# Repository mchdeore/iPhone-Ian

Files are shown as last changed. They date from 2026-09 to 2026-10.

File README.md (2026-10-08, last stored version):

# iPhone Accessibility Robot (`iPhone-Ian`)

A physical robot that operates a **stock, unmodified iPhone** by tapping its
touchscreen, driven by a vision-based AI agent. You give it high-level commands
like `login`, `enter`, or `exit`, and it locates the right on-screen targets,
moves a capacitive stylus to them, and taps — pulling secrets (e.g. login
credentials) from a host-side vault so you never hand-type them again.

> Working title. The repo name (`iPhone-Ian` → "iPhonian") is a placeholder we
> can rebrand later.

## Why a physical robot (and not software)

The phone is treated as an **opaque black box**: no jailbreak, no MDM, no
developer provisioning, nothing installed on it. On a stock iPhone there is no
ADB-style control surface, so a physical actuator that just *touches the glass*
is the most general way to automate an arbitrary device. See
[`specs/00-charter.md`](specs/00-charter.md) for the full rationale.

## The three things set in concrete

1. **Target device: iPhone, 100%.** iOS-only. (The Android survey in
   `research/` is legacy background — see note below.)
2. **Actuation: a tap robot, borrowing heavily from Tapster + the Instructables
   "Screen Tapping Robot."** Reuse existing open designs (Tapster's Push Button
   Robot / Sidekick lineage, the 3D-printable Cartesian gantry) rather than
   reinventing. See [`specs/01-hardware.md`](specs/01-hardware.md).
3. **Training: an ML rig / data-collection app** so the agent learns to drive
   the phone reliably. See [`specs/02-firmware-and-software.md`](specs/02-firmware-and-software.md).

## Repository layout

Split by owner so each of us can find the other's work. Shared material stays at the top.

| Who | Owns | Start here |
|---|---|---|
| **Aria** | Hardware: CAD, parts + sourcing, assembly | [`aria/README.md`](aria/README.md) |
| **Marc** | Software: OCR/vision, training loop, agent, host control, credentials | [`marc/README.md`](marc/README.md) |

```
iPhone-Ian/
├── README.md                      # this file
├── DEVELOPMENT.md                 # staged build pipeline (shared)
├── specs/                         # original specifications (shared)
│   ├── 00-charter.md              # scope, decisions, security, roadmap
│   ├── 01-hardware.md             # hardware research + citations (v2 design: aria/)
│   └── 02-firmware-and-software.md# firmware + software + ML
├── research/                      # background research notes (shared)
├── aria/                          # HARDWARE (Aria)
│   ├── hardware-concept-v2.md     # requirements, design, parts list w/ links, open questions
│   ├── LOG.md                     # dated decisions + to-dos
│   └── cad/v2_0_layout.py         # CoreXY layout model (build123d)
└── marc/                          # SOFTWARE (Marc)
    ├── DEVLOG.md                  # Marc's dev log
    └── parts-v1/                  # v1 gantry CAD (retired by v2)
```

> The research is split into two parts, matching the two specs: **hardware /
> physical build** (`01-hardware.md`) and **firmware / software / ML**
> (`02-firmware-and-software.md`). All reusable-parts research and citations now
> live inside those two docs.

## Relationship to HomeLab

[HomeLab](https://github.com/mchdeore/HomeLab) is the separate, overarching
project: the permanent home PC / Linux server and its CI/CD. This accessibility
robot is intended to be *built on top of* that server (the host that runs the
agent and holds the credential vault lives there), but its research and design
live here, on their own.

## Status

Design stage (2026-10-02). Hardware v2 is proposed: a 2-phone CoreXY gantry, ~34 × 32 × 5 cm, ~C$325 + tax, with
1 phone first for testing. See `aria/hardware-concept-v2.md`. Software planning is under way in `marc/`.
Nothing is built yet.

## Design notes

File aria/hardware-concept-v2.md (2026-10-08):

# Hardware Concept v2: requirements, design, parts

**Author:** Aria (hardware lead) · **Updated:** 2026-10-02 · **Status:** agreed on the 2026-10-02 call. 2-phone capacity, first build tested with 1 phone

This replaces the hardware direction in `specs/01-hardware.md` §0 and Marc's v1 scaffold (now `marc/parts-v1/`). The order is requirements first, then the design, then the parts.

---

## 1. Requirements

| # | Requirement | Drives |
|---|---|---|
| R1 | **2 iPhones of any model** at once (start testing with 1), held so they can't budge. More later = longer rails | Bed size, slot design, expandability |
| R2 | **Screen inputs only:** tap, long-press, swipe/drag. No physical buttons, no multi-touch. Phones are kept awake and charged by other means. | One stylus with hold-down |
| R3 | Typing at **2–3 taps/s** | Motion speed, tap actuator |
| R4 | Lives in a **drawer/cabinet**, runs **quietly**, as **slim** as possible (target: thick laptop) | Height budget, the camera question, drivers |
| R5 | **3D-print as much as possible**, low cost (split between us) | Part strategy, sourcing |

## 2. The camera decision (Marc: this is yours to confirm)

An overhead webcam that sees 2 phones side by side has to sit **~14 cm above the glass** (a typical ~70° webcam
covering ~190 mm), or ~28 cm for 4. Both fail R4 (the machine is ~5 cm tall).

**Proposal: no camera.** Get each phone's screen image directly instead:
- **USB capture.** The phones are plugged in for charging anyway, and macOS can capture an iPhone's screen over
  the cable (QuickTime / AVFoundation). The phone only needs a one-time "Trust this computer".
- **AirPlay mirroring** to a receiver on the host (e.g. UxPlay on Linux), one instance per phone.

Both are built into iOS, so nothing is installed on the phone. On top of fixing the height, it gives:
pixel-perfect input for OCR, no glare or lens calibration, and the tap results show up directly in the feed.
Calibration becomes: tap known gantry points on a Safari calibration page and read where they land.

**Fallback if this doesn't work:** a small camera riding on the gantry that scans each screen in several shots.
It fits the height, but it's slower and makes the OCR harder.

**Question for Marc:** can you get 2 simultaneous screen feeds on your setup (Mac and/or HomeLab)? 1 is enough for first tests.

## 3. Concept

```
 back:  [idlers]━━━━━━ belts ━━━━━━[motor A]
        ═══════ long rail (MGN9) ═══════
        ┃      ┌────┐  ┌────┐         ┃
        ┃bridge│ 📱 │  │ 📱 │         ┃   bridge spans front↔back,
        ┃ +    │    │  │    │         ┃   travels left↔right;
        ┃stylus└────┘  └────┘         ┃   stylus travels along bridge
        ═══════ long rail (MGN9) ═══════
 front:                      [motor B]
```

- **Bed:** 2 printed phone slots (~95 mm pitch, fits up to Pro Max), phones face up in portrait.
  - Each slot has TPU corner pads, a spring-loaded end clamp, a **pocket for the camera bump** (so the phone doesn't rock), and a notch for the charging cable.
  - Clamping is at the **corners and ends only**: side jaws would press the power and volume buttons.
  - More phones = longer rails: set `N_PHONES` in `aria/cad/v2_0_layout.py` and the frame resizes (4 phones = 53 × 32 cm).
- **Motion: CoreXY.** Both motors stay fixed at one end of the frame. The belts pull **both ends** of the bridge
  evenly, so it can't rack, and nothing heavy rides on the bridge, so it stays thin and quiet.
- **Rails:** MGN9 linear rails. They're low, quiet and don't bind, and they replace printed bushings.
- **Tap (Z):** a micro servo lying flat lifts a lever carrying a **spring-loaded conductive stylus** with a **ground
  wire** to controller GND.
  - The spring absorbs thickness differences between models, so one tap height works for all phones.
  - The servo can hold the stylus down for long-press and swipe.
  - A ~10 mm key-to-key hop plus a tap takes ~0.3 s, which meets R3.
- **Controller:** MKS DLC32 (ESP32) running **FluidNC**: CoreXY kinematics and RC-servo Z are set in a config file, with
  no custom firmware. TMC2209 drivers (StealthChop) keep it quiet. (Uno + stock GRBL would need
  two patched firmware forks merged to do CoreXY + servo.)
- **Size:** **~34 × 32 cm footprint, ~5.0 cm tall** (checked in `aria/cad/v2_0_layout.py`: 10 mm under-bridge clearance, every screen corner reachable, no collisions). The minimum height is set by the phones (~9 mm), clearance under
  the bridge, and the bridge itself, so it's thicker than a laptop but fits a deep drawer.

### 3.1 Software ↔ hardware hand-off

The robot exposes only:

```
move(x, y)   tap()   down()   up()   home()
```

These are sent as G-code over USB serial, in mm in the machine frame. Marc builds against this immediately; the
hardware just has to obey it. All intelligence stays on the host.

### 3.2 Parameters the hardware exposes (for Marc's overview)

These are set in FluidNC's `config.yaml` or sent as G-code. The host reads or sets them; nothing is hard-coded in firmware.

| Parameter | Meaning | Typical |
|---|---|---|
| Machine frame | Origin = home corner, X along the phone row, Y along the bridge, mm | after `$H` |
| Travel limits | Soft limits; moves past them are rejected | X ≈ ±86 mm stylus reach (2 phones), Y ≈ ±82 mm |
| Slot origins | Per-phone offset + homography from screen px to machine mm (host-side, from calibration) | 1 per slot |
| Feed rate / accel | Move speed and acceleration | ~150–300 mm/s, ~2000 mm/s² (tune for quiet) |
| Tap depth | Servo "down" angle; the spring absorbs ±3 mm | calibrated per build |
| Lift height | Servo "up" angle: tip ~3 mm above the glass | |
| Dwell | Time held down for a tap vs a long-press | ~60 ms tap, ≥500 ms long-press |
| Swipe | down → `G1` move at a set feed → up | |
| Homing | `$H` against the X/Y endstops at power-on | |
| Status | `?` returns position + state (Idle/Run/Alarm) | polled by the host |

## 4. Review of the current CAD branch

The v1 scaffold (`marc/parts-v1/`, build123d) is a good pipeline, but the design doesn't close:

1. **The heights don't fit together.**
   - The X rods are centred 16 mm up, but phone glass is at ~15 mm (bare) and ~19 mm (cased), so the rods and carriage pass through the phone.
   - The stylus holder hangs 38 mm below the carriage, which puts it through the baseplate.
2. **The Y axis will jam.** One belt drives one side of a ~200 mm bridge riding single 12 mm bushings. That's ~17× the
   bearing length vs the usual ≤2× rule, so it will jam. CoreXY fixes this by driving both ends.
3. **The docs disagree.** `main` says Instructables lead-screw; the branch's §0 says pancake motors, printed bushings and
   a 72 mm X reach; `DEVLOG`/`params.py` say oilite bushings and a 150×160 mm area. The parts-list rod lengths (200/120 mm)
   don't match the model (230/210 mm).
4. **The servo is in two places.** `5_stylus_holder.py` hangs the servo below; the assembly preview mounts it on the side.
5. **Missing:**
   - cable management to the moving carriage
   - grub screws threaded straight into PETG will strip, so they need heat-set inserts or nut traps
6. **The tooling only runs on a Mac:** zsh aliases with hard-coded paths. It needs a cross-platform runner.

**Carries over:** the code-CAD workflow, `params.py` as the single source of dimensions, and the spring-stylus idea.
**Retired:** the rod/bushing gantry parts (1, 3, 4) and the assembly preview.

## 5. Parts to buy: verified listings (checked 2026-10-01, CAD, before tax)

Every listing was opened and its option and price checked. **Choose the variant shown in "Pick".**

### AliExpress

| Part | Link | Pick | C$ | Aria (work) | Marc (work) |
|---|---|---|---|---|---|
| Controller | [MKS DLC32 V2.1](https://www.aliexpress.com/item/1005003528786927.html) | "MKS DLC32 V2.1" (board only) | 26.85 |  |  |
| Drivers | [BIGTREETECH TMC2209 (official)](https://www.aliexpress.com/item/33028050145.html) | 4PCS | 23.21 |  |  |
| Motors | [STEPPERONLINE 17HE08-1004S (official)](https://www.aliexpress.com/item/1005004708155105.html) | 1PC ×2 (23 mm, 1 A, 20 mm shaft) | 24.16 |  |  |
| Servo | [MG90S](https://www.aliexpress.com/item/1005008626768357.html) | 2 pcs, **180°** (360° = continuous, useless) | 5.89 |  |  |
| PSU | [24 V adapter](https://www.aliexpress.com/item/4000521124523.html) | 3A, US Plug, 24V | 10.93 |  |  |
| 5 V buck (servo) | [Mini560 **PRO**](https://www.aliexpress.com/item/1005006537133858.html) | 5 V (PRO = 6–30 V in; plain Mini560 can't take 24 V) | 5.07 |  |  |
| Endstops | [mechanical, with cable](https://www.aliexpress.com/item/1005007505049085.html) | 3 pcs | 3.97 |  |  |
| Rails | [MGN9 (Magic Dragon)](https://www.aliexpress.com/item/1005002721523331.html) | MGN9H: "230mm with Block" ×3 | 39.15 |  |  |
| Bridge | [2020 V-slot (same store)](https://www.aliexpress.com/item/1005003311298946.html) | 240mm, 2020V | 6.39 |  |  |
| Belt | [GT2 rubber/aramid](https://www.aliexpress.com/item/1005008463979470.html) | 6mm, 5 meters | 6.16 |  |  |
| Motor pulleys | [Mellow 20T 5 mm bore (official)](https://www.aliexpress.com/item/33023279793.html) | For 6mm, 2Pcs | 6.86 |  |  |
| Idlers | [GT2 20T 3 mm bore](https://www.aliexpress.com/item/32817328238.html) | "20T W6 B3 GT2 T" ×6, "20T W6 B3 without T" ×4 | 25.62 |  |  |
| Heat-set inserts | [M3 brass](https://www.aliexpress.com/item/1005010325121347.html) | M3 | 7.54 |  |  |
| Screws | [M3 DIN912](https://www.aliexpress.com/item/1005001785690381.html) | M3 × 8, 12, 16, 20, 25, and 50 (×2, corner idler bolts) | ~14 |  |  |
| Nyloc nuts | [M3](https://www.aliexpress.com/item/32798773566.html) | M3 | 2.83 |  |  |
| Shim washers | [M3 0.5 mm](https://www.aliexpress.com/item/1005002046188859.html) | M3, 0.5 mm (idler spacing, inner race only) | 2.38 |  |  |
| T-nuts | [M3 for 2020](https://www.aliexpress.com/item/4000726230157.html) | M3 | 2.94 |  |  |
| Brass tube | [0.25 mm wall](https://www.aliexpress.com/item/1005005307061739.html) | 5 mm OD (4.5 ID fits the stylus tip stem) | ~7.41 |  |  |
| Springs | [0.5 mm wire](https://www.aliexpress.com/item/1005005312536098.html) | ~7 mm OD × 20 mm (over the tube) | ~5.28 |  |  |
| Wire | [silicone](https://www.aliexpress.com/item/1005006250522147.html) | 26AWG, 5 m | 3.78 |  |  |
| Servo extension | [listing](https://www.aliexpress.com/item/1005008268927795.html) | 1to1, 50 cm | 2.29 |  |  |
| DC jack adapter | [listing](https://www.aliexpress.com/item/1005007895939239.html) | female 5.5×2.5 | 2.04 |  |  |
| **AliExpress total** | | | **~235** (~266 with HST) | | |

### Elsewhere

| Part | Where | C$ | Aria (work) | Marc (work) |
|---|---|---|---|---|
| Stylus tips, 6 mm mesh with threaded metal stem | [Amazon.ca PATIKIL 5-pack](https://www.amazon.ca/dp/B0FNX4LB7H) (AliExpress only has Apple Pencil nibs, which are active and won't work) | 8.49 |  |  |
| Rail risers, 6061 10×20 mm, 2 pieces ~240 mm (one 500 mm bar cut in half) | [Amazon.ca COYOUCO 10×20×500](https://www.amazon.ca/dp/B0GS1P1J79) ×1, or Metal Supermarkets (Kitchener) | ~27 |  |  |
| Base plate, 3 mm aluminium ~341×320 with slotted holes | JLCCNC quote **after** the plate CAD exists | ~50 incl. shipping |  |  |

**Whole build ≈ C$325 + tax, split between Aria and Marc.** Both of us have 3D printers and essentially free filament.

**Work sourcing:** each of us ticks what we can get through work in the **Aria (work)** / **Marc (work)** columns.
Anything ticked comes off the order.

**Printed (Centauri, CF-PETG / TPU):** corner idler posts + top plates + side walls, motor clamp bars + legs, motor B spacer,
bridge end blocks + top plates, toolhead plate + lever + stylus sleeve, belt clamp, endstop mounts, 2 phone slots,
cable guides, feet, controller box.

**Assembly notes:**
- Mount motor pulleys **hub-up** (teeth toward the motor) so they line up with the belts.
- Every idler bolt is clamped **top and bottom**. Shim washers touch only the bearing's inner race.
- Confirm on arrival which pin on the DLC32 drives the servo and how the board takes power (barrel jack vs screw terminal).

**Security:** run the controller over USB only, with its Wi-Fi off. Remote access goes through the host (SSH / WireGuard / Tailscale).
FluidNC's network control has no real authentication.

## 6. Sourcing

- **JLCCNC** is the default for metal (price). Bundle the JLCMC rails, pulleys and fasteners into the same order.
- **SendCutSend** only for rush parts.
- **AliExpress** for electronics, motors, motion parts and hardware (one order; rails + extrusion ship together from Magic Dragon).
- **Base from day one is a 3 mm aluminium plate cut by JLCCNC.** Rail-riser, motor and slot holes are **slots, not round holes**,
  so a few mm of CAD error is adjusted out instead of forcing a reorder. Order it only after the assembly is checked in Onshape.
  Later upgrades: a bent aluminium tray (base + raised rail ledges in one part), a bent-channel bridge, motor plates.
  Later, possibly a JLC flex-PCB ribbon to the carriage.
- Keep precision holes on flat sections, not ones that depend on a bend's position.

## 7. Open questions for Marc

1. Do 2 simultaneous screen feeds (USB or AirPlay) work on your setup? This decides the camera question.
2. Bare phones only, or cases too? (The spring absorbs ~3 mm; cases also widen the slots.)
3. ~~OK for me to take over the CAD branch?~~ **Agreed 2026-10-02.** Repo split into `aria/` and `marc/`.
4. ~~Budget?~~ **Agreed 2026-10-02:** ~C$325 + tax, split between us.
5. Is the hand-off in §3.1 enough for your side?
6. Security: OK with USB-only to the controller and all remote access through the host?

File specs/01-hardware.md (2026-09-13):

# Hardware Build Specification

**Scope:** everything physical — the machine, its motion, the tap, the phone
mount, the camera, and the CAD files to build it all. Firmware and code live in
[`02-firmware-and-software.md`](02-firmware-and-software.md).

> All external links are collected with citations in §11. User-supplied CAD links
> are tagged `[user-provided]` and listed in §5.

---

## 0. FINAL LOCKED DESIGN — v1 (2026-09-09)

**Locked by the owner.** Priorities: **quiet, small, easy to work on** (not powerful,
not high-accuracy — the camera closes the loop, §8). This section supersedes any
conflicting option below; the multi-touch / two-arm (Sidekick) path and the
**lead-screw** drive are **retired** for v1. §§1–11 are retained as research/rationale.

### 0.1 Architecture

A **belt-driven Cartesian gantry** with a single effector. One motor per axis — maps
directly onto GRBL, zero custom firmware.

- **Y axis** (long, ~150 mm reach): two 8 mm smooth steel rods along the phone's
  length carry a cross-beam on **printed bushings**; Y motor is fixed to the frame.
- **X axis** (short, ~72 mm reach): two short 8 mm rods on the beam; a **pancake**
  NEMA 17 rides here on printed bushings (minimizes moving mass → quieter, smaller).
- **Z / tap:** MG90S metal-gear servo on the X carriage, stylus arm on the horn.
- Grounded capacitive stylus tip (ground wire to controller GND — mandatory, §3.1).

### 0.2 Print-max BOM — buy only precision-critical parts

**Philosophy:** 3D-print everything structural (free); buy only what carries precision
or can't be printed. The **running surface is a bought 8 mm smooth steel rod**; the
bushings that ride it are **printed** (steel rod = the precision, plastic-on-steel
bushing = free and quiet — no stick-slip). `ponytail:` printed bushings wear under
continuous use — ceiling is finite service life; upgrade path is drop-in IGUS DryLin
bushings of the same 8 mm bore, no redesign.

**Buy (precision-critical / unprintable):**

| Part | Qty | Why bought |
|---|---|---|
| NEMA 17 pancake stepper, 0.9–1.0 A | 2 | Electromagnetic |
| MG90S metal-gear micro servo (tap/Z) | 1 | Electromechanical |
| Arduino Uno + CNC Shield V3 | 1 | Electronics |
| TMC2209 "silent" driver (StealthChop2) | 2 | Quiet stepping |
| 12 V regulated PSU (~2 A) + 12→5 V buck | 1 | Clean power, servo isolation |
| **8 mm smooth steel rod** (2×~200 mm Y, 2×~120 mm X) | 4 | **The precision running surface** |
| GT2 6 mm belt | 1 | Reinforced — can't print |
| 20T bore-5 GT2 pulleys + 623 idler bearings | set | Precision tooth mesh / rolling |
| Microswitch endstops (X-min, Y-min) | 2 | Repeatable `$H` homing |
| M3 heat-set inserts + M3/M5 fasteners | set | Serviceable printed joints |
| Capacitive stylus tip + ground wire | 1 | The effector |
| Rubber/sorbothane feet (or print in TPU) | 4 | Isolate base = biggest quiet win |

**Print (free):** baseplate, Y cross-beam, X carriage, **the linear bushings**, all
motor/idler/endstop mounts, belt clamps + tensioner, phone cradle (tripod-clamp
model, §5.1), camera arm, stylus arm. Optionally print GT2 pulleys, but bought metal
ones avoid tooth backlash for ~$2.

**Controller/software link:** USB serial to GRBL now; ESP32 + FluidNC is the drop-in
upgrade if USB-C / wireless is wanted later (sw spec §4.1).

### 0.3 Reused CAD (from §5.1) / retired items

- **Reuse:** parametric NEMA 14/17 mount (→ motor mounts), SG90 model (→ MG90S mount
  fit), tripod phone clamp v2 (→ phone cradle), **linear sliding system + DSLR slider
  (→ rod + printed-bushing carriage reference — now directly relevant)**.
- **Retired (lead-screw):** screw+stepper coupling, MK4 Z-screw motor cover.

### 0.4 Approximate cost (print-max; excl. phone / camera / laptop; printing free)

| Group | Items | ~USD |
|---|---|---|
| Core electronics + motors | Uno+shield, 2× TMC2209, 2× pancake NEMA 17, MG90S, 12 V PSU, buck | **~$79** |
| Precision motion | 4× 8 mm steel rod, GT2 belt + pulleys + 623 idlers, 2× endstops | **~$23** |
| Fasteners + effector + feet | heat-set inserts/screws, stylus tip + wire, rubber feet, USB cable | **~$18** |
| **Total** | | **~$120** |

Low–high range **≈ $100–150** depending on source (AliExpress budget ↔ Amazon/genuine).
Down from the ~$155 MGN9 build by **printing the bushings + structure** and letting a
cheap steel rod carry the precision. Figures are approximate hobby-market estimates,
not live quotes — a sourced, link-by-link list is the next deliverable.

---

## 🎯 1. Design source of truth (current)

**Instructables — "Screen Tapping Robot"** → https://www.instructables.com/Screen-Tapping-Robot/

Our mechanical baseline. A 3D-printable, stepper-driven **Cartesian XY gantry**
with a stylus that taps the screen — exactly our target architecture, and the
maker reports it working.

**Verified from the build description:**
- **X-axis:** NEMA 17 stepper driving a **lead screw**, riding on **two
  8 mm × 300 mm stainless precision shafts** with **linear ball bearings**; the
  X-axis carries the Y-axis + stylus (built stiff on dual shafts for that reason).
- Cartesian lead-screw motion (not delta, not CoreXY).

**Still to extract from the build page** (Instructables blocks scraping — pull by
hand): Y-axis mechanism + motor, Z/stylus actuation, controller + firmware,
grounding, full BOM, STL/CAD files, work-area dimensions.

---

## 2. System architecture

Five physical subsystems. Each maps to reusable CAD/parts in §4–§5.

| Subsystem | Function | Baseline choice |
|---|---|---|
| **X axis** | Move stylus left/right across screen | NEMA 17 + lead screw on dual 8 mm shafts (SoT) |
| **Y axis** | Move stylus up/down the screen | NEMA 17 + lead screw or belt (TBD from SoT) |
| **Z / tap** | Bring stylus into contact & lift | Servo pen-lift **or** passive spring-Z stylus (§6) |
| **Phone mount** | Hold an iPhone rigidly & repeatably | Adjustable printed clamp (§5) |
| **Camera mount** | Fixed overhead view of the screen (the agent's eyes) | Printed arm / slider rail (§5) |

Design driver: **rigidity + repeatability**, because calibration (camera→screen→
gantry) is the real accuracy bottleneck, not raw motor resolution (§8).

---

## 3. Prior-art lessons we inherit (free knowledge)

From **Tappy / Tapsterbot** (delta-robot phone tappers — different kinematics, same
touch problem). See software spec §2 for their reusable *code*.

1. **Grounding is mandatory — confirmed by multiple builders.** The stylus must be
   electrically tied to the controller/USB ground or the capacitive screen won't
   register touches. Tappy's own docs: *"Make sure that phone recognises stylus
   touches (it must be grounded to arduino GND)."* [guntiss/tappy] **→ We design an
   explicit ground path from day one.**
2. **Joint slop kills accuracy.** Tappy fixed positioning slop by swapping
   ball-joints → neodymium magnets and metal → plastic linkages. A stiff Cartesian
   gantry sidesteps most of this — an argument for our architecture.
3. **Contact is capacitive, not pressure-based** (see
   `../research/02-mechanical-architecture-notes.md`). We only need *consistent*
   contact geometry, not force — so a light, repeatable tap depth is enough.

### 3.4 Tapster design lineage — borrow as much as possible ⭐

Tapster (https://tapster.io, by Jason Huggins — creator of Selenium/Appium) is a
company that has worked on **almost nothing but phone-tapping robots for years**,
and much of it is open. **Policy: reuse their designs wherever we legally can**
(check each repo's license), rather than reinventing.

Their lineage, simplest → most capable:

- **Push Button Robot** — a small-footprint, minimal, ~two-rail/two-track tapper.
  *[user-reported; verify specifics on tapster.io + the `tapsterbot` GitHub org.]*
  **This is our most attractive MVP target:** tiny, few parts, and easy to drive
  deterministically (see sw spec §4.1). Start here, scale up only if needed.
- **Sidekick** — **two independent arms**, each with its own Z-axis servo (the host
  maps left arm = servo `s3`, right arm = servo `s6`). Two effectors ⇒ a path to
  **2-point multi-touch** (pinch/rotate) later. Web controller repo:
  https://github.com/tapsterbot/controller
- **Tapster / Tapster-2** — the flagship **delta** tapper (open hardware + software).
- **Valet** — their **current Raspberry-Pi-based** product. Notable because it puts
  the **Pi as the host** — the same split we plan (Pi/HomeLab host drives a dumb
  controller).
- **BitBeamBot** — the ancestor that started the lineage (built to play Angry Birds).

**Strategy:** prototype at **Push Button Robot** scale/simplicity, reuse Tapster's
open hardware + host stack, and only move to a Cartesian gantry or a two-arm
(Sidekick-style) rig if the task demands larger reach or multi-touch. Links in §11.

---

## 4. Mechanics — reuse ecosystems (don't design linear motion from scratch)

- ⭐ **OpenBuilds** — V-Slot™ / C-Beam™ extrusion, wheels, lead screws, NEMA 17
  mounts, gantry plates. CC BY-SA; large parts market. https://openbuilds.com
- ⭐ **OpenBuilds ACRO** — a pen-plotter-sized XY gantry kit ≈ our machine;
  adaptable to any size. Assembly: [Maker Hardware ACRO manual]; ACRO pen-plotter
  build w/ GRBL + Pi: [ACRO Openbuilds Pen Plotter].
- **openBrushograph** — 3D-printable XY gantry + Z, FreeCAD/OpenSCAD sources.
  https://github.com/openBrushograph/openBrushograph_hardware
- **CNC pen-plotter references** — https://github.com/DAguirreAg/CNC-pen-plotter ·
  https://github.com/thrly/pen-plotter-resources
- **openbuilds-parts** (OpenSCAD brackets) — https://github.com/mhgreen/openbuilds-parts

**Decision to make:** keep the SoT's printed shaft + lead-screw frame (cheapest,
fully printable) **vs.** OpenBuilds extrusion (stiffer, faster to assemble). Our XY
load is a featherweight stylus, so recommend prototyping on **ACRO** to de-risk
motion, then optimize cost.

---

## 5. CAD file library

Ready-to-use models mapped to subsystems. **Editability:** GrabCAD models are often
**STEP** (parametric-editable); Printables are usually **STL** (mesh). Verify
license on each before use.

### 5.1 User-provided links `[user-provided]`

| Part | Use in our build | Link | Notes |
|---|---|---|---|
| Medium-format CNC machine w/ ATC spindle | Reference for a full XY(Z) gantry + mounts | https://grabcad.com/library/custom-designed-medium-format-cnc-machine-with-atc-spindle-1 | Bigger than we need; harvest gantry/mount geometry |
| **SG90 micro servomotor** | The **tap (Z) actuator** model for assembly fit | https://grabcad.com/library/sg90-micro-servomotor-1 | Pairs with ServoEasing in sw spec |
| Rubik's Cube solver (full setup) | Reference: multi-motor + gripper + frame + vision | https://grabcad.com/library/rubik-s-cube-solver-full-setup-1 | Great CV-robot mechanical precedent |
| **Parametric NEMA 14/17 stepper mount** | **X/Y motor mounts** (parametric = resize to our frame) | https://grabcad.com/library/parametric-stepper-motor-nema-14-17-mount-1 | Directly reusable |
| **DSLR slider module** | **Linear axis** reference (carriage + rail) | https://grabcad.com/library/dslr-slider-module-1 | Camera-slider = a single linear axis |
| **Linear sliding system** | **X/Y linear-motion** carriage/bearing block | https://grabcad.com/library/linear-sliding-system-1 | Core motion element |
| **Screw + stepper motor coupling** | Couple NEMA 17 shaft → lead screw | https://www.printables.com/model/404241-screw-and-stepper-motor-coupling | Directly reusable |
| **MK4 Z-screw motor cover** | Tidy/protect the Z lead-screw + motor | https://www.printables.com/model/454773-mk4-z-screw-motor-cover | Cosmetic/protective |
| **Adjustable tripod phone clamp v2** | The **iPhone mount** (adjustable width) | https://www.printables.com/model/25969-tripod-mobile-phone-clamp-v2 | Directly reusable for phone cradle |

> Status: links recorded as provided; **not yet individually opened/verified**
> (GrabCAD/Printables may gate downloads behind login). Verify geometry, scale, and
> license before printing. Mesh (STL) parts may need re-modeling if dimensions must
> change — prefer the STEP/parametric ones for load-bearing structure.

### 5.2 Model libraries to search for the rest

- **Printables** https://www.printables.com · **GrabCAD** https://grabcad.com ·
  **Thingiverse** https://www.thingiverse.com · **Thangs** https://thangs.com
- **Hardware w/ CAD (for a correct BOM):** McMaster-Carr, Misumi (every
  screw/bearing/shaft as a STEP).

### 5.3 CAD tools

- **FreeCAD** (parametric, open) · **OpenSCAD** (code-CAD; great for parametric
  brackets — openBrushograph uses both) · **Onshape** / **Autodesk Fusion** (GUI).

---

## 6. Tap (Z) actuation — options

The tap is the one truly custom motion. Three routes (hardware side; firmware in sw
spec §3):

1. ⭐ **Servo pen-lift** (SG90 + ServoEasing) — controlled, repeatable tap depth;
   reuses the entire pen-plotter ecosystem (GRBL servo-Z forks). Matches the
   user-provided SG90 CAD.
2. **Passive spring-Z stylus** (Tappy-style) — no Z motor; the XY frame lowers a
   sprung stylus. Simplest, but tap force/engagement is fixed by geometry.
3. **Solenoid tapper** — snappy single taps; poor for press-and-hold/drag.

**Recommendation:** servo pen-lift (route 1). It also enables long-press/drag by
holding Z-down while XY moves — needed for swipes and `type` on the keyboard.

Stylus tip: conductive capacitive stylus tip **with the mandatory ground wire**
(§3.1) back to controller/USB GND.

---

## 7. iPhone-specific mechanical notes

- **Flat vs. curved glass:** a fixed-angle stylus tuned for the flat center may miss
  near curved "waterfall" edges (surface normal changes). Recent iPhones trend
  flat, which helps. Pick a first target model and measure. *(Inference — verify on
  hardware.)*
- **Screen protectors:** thin ones don't meaningfully block capacitive sensing;
  thick/air-gapped ones can. Test with the actual phone + stylus.
- **Reachability:** the work area must cover the **full screen including the
  on-screen keyboard** (bottom edge) for credential typing.

---

## 8. Accuracy target

Sub-mm gantry accuracy is easily achievable and is **well within** iOS's comfortable
touch-target size (~44 pt). As Tappy found, **mechanical precision is not the
limiter — calibration is.** Spend effort on the camera→screen→gantry transform (sw
spec §4), not on exotic motors.

---

## 9. Bill of materials (direction, not final)

### 9.1 Recommended starter parts — "does the motor/controller/camera matter?"

**Short answer: mostly no.** Because (a) an overhead camera **closes the loop** and
corrects positioning error, and (b) iOS touch targets are large (~44 pt ≈ 8 mm),
**open-loop precision barely matters.** Pick parts for cost and convenience, not
spec. Concretely:

**Camera — just use a USB webcam. ✅**
- Any UVC 1080p webcam is plenty (a Logitech C920-class cam is the easy default).
- What *actually* matters, in order: **(1) rigid mount** (camera must not move
  relative to the phone — this preserves calibration); **(2) locked focus** — set
  manual focus once, or lock autofocus, since the geometry is fixed ("set-and-lock
  holds calibration"); **(3) glare control** — a glossy screen reflects; angle the
  cam slightly and diffuse the lighting. Resolution, fps, and shutter type are
  non-issues (static scene, we act on still frames).
- Don't buy a machine-vision camera — overkill.

**Motors & drivers — "quiet" is a *driver* choice, not a motor choice:**
- ⭐ **NEMA 17 stepper + TMC2209 "silent" driver** — the pick for your priorities.
  TMC2209's **StealthChop2** drives a smooth sinusoidal current instead of the
  A4988's harsh on/off chopping, eliminating the classic stepper whine (it's *the*
  standard silent-3D-printer upgrade). It's a **pin-compatible drop-in** for the
  A4988 slot on the CNC Shield and runs with GRBL in standalone step/dir mode.
  ~$4–9 per driver.
- **Avoid the 28BYJ-48 for this build.** It's the cheapest motor but the **janky**
  one — geared backlash, low build quality, less reliable. You said you'd pay to
  avoid jank; skipping it is step one.
- **SG90 micro servo for the tap (Z)** — cheap, but servos **buzz** while holding.
  Silence it by (a) powering the servo from its **own 5V supply** (never the Uno's
  5V rail), and (b) **detaching / cutting the PWM signal when idle** so it's quiet
  between taps. A metal-gear micro servo (MG90S) also helps.
- *Why precision is a non-issue:* microstepping smooths motion but isn't
  super-accurate; real open-loop precision needs encoders/gearing we don't need,
  because the camera measures where we actually landed and corrects (sw spec §5.1).

**Controller — the cheap standard stack:**
- ⭐ **Arduino Uno + CNC Shield V3 + TMC2209 (silent) drivers, running GRBL**, driven
  from the **laptop over USB** (G-code). Industry-standard, endlessly documented; the
  TMC2209s drop straight into the A4988 slots. Put the tap **servo on a spare pin
  with its own 5V supply** (don't power a servo off the Uno's 5V).
- The Raspberry Pi is optional and belongs on the **host** side (running vision +
  agent), *not* as the motor controller — keep the Uno+GRBL as the dumb,
  deterministic motion box (sw spec §4.1).

### 9.1.1 Tuned build: cheap + quiet + not-janky (your call, +~$50)

Spend the extra exactly where it buys **silence + reliability**, in priority order:

1. **TMC2209 silent drivers ×2** (~$10–18/pair vs ~$3 for A4988) — the biggest quiet
   win; drop-in on the CNC shield. **Do this one for sure.**
2. **Quality linear motion** — a pair of **MGN9 mini linear rails** (or good V-slot
   wheels) instead of cheap 8 mm rod + LM8UU bushings, which rattle/bind. ~$20–30.
   Removes most of the "jank."
3. **Small regulated 12 V PSU** (~$8) — steady power = less coil whine and more
   reliable than a random wall-wart.

Extra ≈ **$40–55**. Everything else stays rock-bottom (Uno, CNC shield, 2× NEMA 17,
GT2 belt or lead screw, SG90, printed parts). Result: a small rig that homes
reliably, moves near-silently (StealthChop), and doesn't rattle — exactly "quiet,
reliable, easy to work with, not powerful, not high-accuracy." The vision loop
(sw spec §5.1) covers the accuracy you're intentionally not paying for.

### 9.2 Rough cost (direction)

| Class | Approx. cost | Basis |
|---|---|---|
| SoT printed frame (delta/gantry + servos/steppers + stylus) | ~$80–150 | TestDevLab Tappy / SoT |
| OpenBuilds ACRO XY gantry (steppers + extrusion + plates) | ~$150–300 | Inferred from kit pricing |
| + overhead camera (USB webcam) + printed phone clamp | +$20–60 | Inference |
| Electronics (Arduino Uno + CNC Shield + drivers + servo) | ~$30–70 | TMC2209 (silent) or A4988; + SG90 |
| ⭐ **Quiet/reliable upgrades** (TMC2209 ×2 + MGN9 rails + regulated PSU) | +$40–55 | §9.1.1 — your +$50 budget |

A sourced, quantized BOM is a Phase-1 deliverable once §4's frame decision is made.

---

## 10. Open hardware decisions

- [ ] Frame: printed shaft/lead-screw (SoT) vs. OpenBuilds ACRO extrusion.
- [ ] Z: servo pen-lift (recommended) vs. passive spring-Z vs. solenoid.
- [ ] First target iPhone model (screen size/curvature → clamp + calibration).
- [ ] Camera: fixed overhead webcam spec + mount rigidity.
- [ ] Controller board (ties to firmware route — sw spec §1).

---

## 11. Citations & links

**Design source of truth**
- Screen Tapping Robot — https://www.instructables.com/Screen-Tapping-Robot/

**Prior-art robots (mechanics + grounding lessons)**
- Tapster (Jason Huggins) — https://tapster.io · https://github.com/tapsterbot/tapsterbot
- Tapster product lineage — Push Button Robot / Sidekick / Tapster-2 / Valet / BitBeamBot (see https://tapster.io and the https://github.com/tapsterbot org)
- Sidekick web controller — https://github.com/tapsterbot/controller
- Tapster overview — https://intorobotics.com/tapster-open-source-robot-to-test-mobile-applications-on-a-smartphone/
- Tappy (TestDevLab forks) — https://github.com/guntiss/tappy · https://github.com/merinsTDL/tappy · https://github.com/DeMaCS-UNICAL/tappy-original

**Mechanics ecosystems**
- OpenBuilds — https://openbuilds.com
- ACRO assembly — https://makerhardware.net/knowledge-base/build-manuals/cnc-machines/acro-cnc-mechanical-kit-assembly-instructions/
- ACRO pen-plotter (GRBL + Pi) — https://www.instructables.com/ACRO-Openbuilds-Pen-Plotter-Arduino-With-GRBL-and-/
- openBrushograph — https://github.com/openBrushograph/openBrushograph_hardware
- CNC pen plotter — https://github.com/DAguirreAg/CNC-pen-plotter
- pen-plotter-resources — https://github.com/thrly/pen-plotter-resources
- openbuilds-parts (OpenSCAD) — https://github.com/mhgreen/openbuilds-parts

**User-provided CAD** — see §5.1 table.

**CAD tools & libraries**
- FreeCAD https://www.freecad.org · OpenSCAD https://openscad.org · Onshape https://www.onshape.com
- Printables https://www.printables.com · GrabCAD https://grabcad.com · Thingiverse https://www.thingiverse.com · Thangs https://thangs.com

**Parts selection (§9.1)**
- Webcam focus: set-and-lock manual focus holds calibration — https://commonlands.com/blogs/technical/autofocus-machine-vision · lock UVC autofocus — https://stackoverflow.com/questions/55923443/how-to-lock-autofocus
- 28BYJ-48 suitability / accuracy (~5% non-cumulative) — https://www.quora.com/Is-a-28BYJ-48-stepper-motor-good-for-a-CNC-application · https://www.rajguruelectronics.com/Product/1467/28BYJ-48%20-%205V%20Stepper%20Motor.pdf
- Microstepping smooths but isn't precise — https://forum.pololu.com/t/inconsistent-step-size-with-nema-17-motor-and-tic-t825/21499
- NEMA 17 + A4988 wiring guide — https://racheldebarros.com/arduino-projects/control-nema17-with-a4988-arduino-wiring-and-code-guide/
- Arduino Uno + CNC Shield V3 + GRBL — https://www.diyengineers.com/2023/01/05/grbl-with-arduino-cnc-shield-complete-guide/ · servo on CNC shield — https://forum.arduino.cc/t/4-stepper-and-2-servo-with-cnc-shield/984330
- TMC2209 silent driver (StealthChop2, drop-in for A4988) — https://www.digikey.com/en/product-highlight/t/trinamic/tmc2209-ultra-silent-motor-driver-ic · silent-upgrade explainer — https://blog.uavmodel.com/3d-printer-silent-board-upgrade-tmc2209-drivers-stealthchop-and-noise-reduction-2026/
- SG90 servo buzz (external supply + don't hold against end stops) — https://forum.arduino.cc/t/sg90-servo-motor-mkaing-buzzing-noise/615492 · https://forum.arduino.cc/t/buzzing-sg90-servo/562799

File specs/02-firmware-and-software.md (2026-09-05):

# Firmware, Software & Machine-Learning Specification

**Scope:** everything that runs as code — on-robot **firmware**, the **host**
control software, **computer vision**, the **AI agent / ML**, command handling, and
credential security. Physical build lives in
[`01-hardware.md`](01-hardware.md).

> Guiding principle (see `00-charter.md`): the mechanics are commodity. The novel
> work is **calibration** (camera→screen→gantry) and the **command→action agent
> with safe credential handling**. Everything else, reuse or fork.
> All links cited in §10.

---

## 1. Layered architecture & the three firmware routes

```
 command ("login")           ┌─────────────── HOST (HomeLab box) ───────────────┐
        │                     │  Agent (planning)                                 │
        ▼                     │   ├─ Perception: camera → OCR/VLM/grounding       │
 [ Agent / planner ] ─────────┤   ├─ Calibration: screen px → gantry XY (homog.)  │
        │  target XY + tap    │   ├─ Credential vault (secrets)                   │
        ▼                     │   └─ Motion client → serial/USB → controller      │
 [ Host motion client ]  ─────┘                                                   
        │  G-code / protocol
        ▼
 [ Controller firmware ] → stepper drivers + servo → MOTION → stylus taps glass
```

**Firmware route decides how much we build vs. reuse:**

| Route | Firmware | Host does | Reuse | Verdict |
|---|---|---|---|---|
| **A. GRBL/FluidNC** ⭐ | Off-the-shelf CNC firmware; **Cartesian kinematics built in** | Stream G-code | Highest — no firmware to write | **Recommended** for our Cartesian gantry |
| **B. Firmata (Tapster-style)** | StandardFirmata (dumb pin I/O) | ALL logic incl. kinematics | Reuse Tapster's host stack directly | Best if we lift Tapster wholesale |
| **C. Custom Arduino** | AccelStepper + ServoEasing + custom serial | Send high-level cmds | Libraries only | Most control, most work — avoid unless needed |

Because our machine is **Cartesian**, GRBL maps trivially (X→X motor, Y→Y motor,
Z-servo→tap); Route A means **zero custom firmware**.

---

## 2. Reuse from Tapsterbot / Tappy (the "steal the firmware" plan)

**Reality check on what's open:** Tapster's *on-device firmware* is just
**StandardFirmata** (open, shipped with the Arduino IDE) — the intelligence
(delta inverse-kinematics, calibration, control API, Appium bridge) lives in its
**open-source Node.js host software**. So "steal the firmware" in practice means
**reuse the open host stack + the Firmata approach**, not a secret sauce binary.

**Directly reusable from Tapster/Tappy:**
- ⭐ **Browser-based calibration** — load a page on the phone, touch registers
  screen coords at the host; solves the screen↔robot mapping without installing
  anything on the phone. (Tappy: `http://server_ip/cal`.) [guntiss/tappy]
- ⭐ **Grounding requirement** baked into their setup notes — *"stylus must be
  grounded to arduino GND"* (see hardware spec §3). [guntiss/tappy]
- **Control server + API** and **Appium integration** (drive it like a test rig).
- **Record-and-play** tool for scripted sequences. [merinsTDL/tappy]
- Delta **inverse-kinematics** — *only if we ever go delta*; our Cartesian gantry
  doesn't need it (GRBL handles motion). Standalone lib if needed:
  tinkersprojects/Delta-Kinematics-Library.

**Repos:** hugs/tapsterbot (original) · pylapp/tapsterbot (maintained fork) ·
merinsTDL/tappy · guntiss/tappy · DeMaCS-UNICAL/tappy-original ·
DeMaCS-UNICAL/BrainyBot (CV taps a phone to *play games* — closest full
perception→tap precedent).

**Plan:** Route A firmware (GRBL) for motion + steal Tapster's **calibration page**
and **control/record ideas** at the host layer.

---

## 3. Firmware building blocks (by route)

### Route A — GRBL / FluidNC (recommended)
- **GRBL** (Arduino Uno/Atmega328) — https://github.com/gnea/grbl
- **FluidNC** (ESP32; YAML config, WiFi/BT, web UI) — https://github.com/bdring/FluidNC
- **Servo-Z "pen up/down" = our tap** (already solved):
  bdring/Grbl_Pen_Servo · vankesteren/grbl-servo · ArcaEge/grbl-28byj-48-pen-plotter-servo

### Route C — custom Arduino libraries (only if we skip GRBL)
- **AccelStepper** (Mike McCauley) — the standard accel/decel stepper lib.
- **SpeedyStepper** (Stan-Reifel) — speed-optimized alternative.
- **StepperDriver** (laurb9) — A4988/DRV8825/DRV8834/DRV8880, accel + microstep.
- **ServoEasing** (ArminJo) — smooth servo motion (linear/cubic/bounce…), works with
  the Arduino Servo lib **and PCA9685** — ideal for controlled tap depth.
- **PCA9685** 16-ch PWM driver + Adafruit_PWMServoDriver — if we later want multiple
  servos (e.g. multi-touch with two stylus tips).

### Stepper drivers (hardware interface)
- **A4988** (up to 1/16 microstep) / **DRV8825** (up to 1/32) on a CNC-shield —
  standard, cheap. RobTillaart/DRV8825 lib for direct control if needed.

---

## 4. Host-side control (HomeLab box → controller)

- ⭐ **Programmatic (for the agent):** thin Python **pyserial** G-code streamers
  with flow control — Sam-Freitas/python_to_GRBL · jonkensta gist (buffer-aware
  streaming). This is what the agent calls to move + tap.
- **Manual jog / calibration GUI:** Universal G-Code Sender (winder/UGS, Java) ·
  bCNC (Python, runs on a Pi) · gSender (Sienci, grblHAL).

Motion client exposes primitives to the agent: `move(x,y)`, `tap()`, `swipe(...)`,
`type(text)` (per-key taps). Under the hood these emit G-code (Route A).

### 4.1 "Can the Pi/Arduino just accept simple code inputs?" — yes ⭐

This is the split you want: **dumb, deterministic motors; smart host.** Two proven,
simple ways to make an Arduino/ESP32 accept coordinate commands from a Raspberry Pi
or PC:

1. **Firmata + pyFirmata / Johnny-Five (Tapster's exact approach).** Flash
   **StandardFirmata** (dumb pin/servo I/O) to the Arduino; the **Pi/host** runs a
   few lines of Python (**pyFirmata**) or Node (**Johnny-Five**) and commands the
   servos/steppers directly. Tapster drives it literally like this — a REPL where
   `go(0,0,-140)` moves the effector. The Arduino holds **no logic**; the host code
   + ML decide everything. *(Caveat: no on-board logic; motion timing depends on the
   host + USB link — perfectly fine for tapping.)*
2. **GRBL / FluidNC + G-code (recommended once we use steppers).** Flash GRBL; the
   host sends plain text lines — `G0 X100 Y50` to move, then a servo-Z line to tap.
   The controller handles stepping/acceleration **deterministically on-device**.

**Minimal input contract — start here (the "simple thing we know will work"):**

```
host → controller:   move(x, y)        # go to screen/robot coordinate
                     tap()             # Z down, brief dwell, Z up
                     (later) down()/up()  # for press-hold, swipe, drag
```

That is the **entire** firmware interface. Everything hard — *where* to tap and
*reading* the screen — lives in host code + ML (§5–§7), never in the firmware. Build
this dumb interface first, prove it moves to a coordinate and taps reliably, then let
the vision/agent stack layer on top.

---

## 5. Computer vision — camera → screen coordinates

The phone is a black box; the overhead camera is the only sensor. Both sub-problems
are stock **OpenCV**:

- ⭐ **Homography / four-point perspective warp** — reproject the angled camera view
  into a flat screen rectangle, then map screen px → gantry XY. This IS the
  calibration transform. `cv2.findHomography` / `getPerspectiveTransform`.
  - Tutorial (UI-scraping use case): [TheLinuxCode perspective warp]
  - Homography-from-reference-image: RaubCamaioni/OpenCV_Position
- **Camera intrinsic calibration** (undistort first) — OpenCV calib3d tutorial.
- **Auto-detect the phone rectangle** — OpenCV forum "Detecting a smartphone screen".

**CV-robot reference architectures (CV → serial → motion), study for the pattern:**
- Shen-Kev/**Petri-Dish-Gantry** — vision tracking drives a gantry (general-purpose
  tracking+motion arch).
- tunmaker/**Delta-Robot-Project** — image processing (EmguCV) → Arduino over USB
  serial, "like a CNC machine".
- himadripoddar/**Pick-and-Place-3-DOF** (OpenCV color detect) ·
  Mowbray-R-V/**Gantry_control-pose_estimation** · the Rubik's-cube-solver CAD in
  hardware §5.1 is this same class of CV-guided multi-motor rig.

### 5.1 Target-practice trainer app (calibration + benchmark + optional reward) ⭐

A tiny app that flashes a target on the phone, lets the robot try to tap it, and
**measures where the tap actually landed** — the single most useful test harness in
the whole project. It does triple duty:

1. **Calibration data** — a known displayed target + the measured touch point is
   exactly the correspondence needed to solve/refine the screen↔robot homography (§5).
2. **Accuracy benchmark** — score = how close the tap was; track it across builds.
3. **Optional training reward** — the same score can drive learning (see note).

**Build it the lazy way — a web page, not a native app:**
- A local page (served from the laptop) shows a dot/square at a known coordinate.
- Capture the real touch with standard JS **`touchstart`/`touchend` → `Touch`
  clientX/clientY** (MDN Touch events) and send it back to the host over
  WebSocket/HTTP.
- **No App Store, no install, works in mobile Safari** — this is precisely Tapster/
  Tappy's browser calibration page (§2). Reuse theirs as a starting point.

**Scoring rubric (your idea, made concrete):**
```
error = distance(tap_point, target_center)      # in screen mm/px
score = max(0, 1 - error / target_radius)        # 1.0 = dead center, 0 at edge
if tap outside phone screen bounds:  score = large negative  # "missed the phone"
```
Loop: show target → robot taps → measure → score → (refine transform) → next target,
across a grid of positions. Median score = the rig's calibration quality.

> **Honest note on "reinforcement learning":** full RL (reward-driven policy
> training) is *more machinery than this needs* and is hard to get working. The same
> hit/score loop gets you 95% of the value as **plain closed-loop calibration**:
> measure the systematic error and update the homography / add a small correction
> offset. Start there. Treat RL as an optional later layer only if nonlinear or
> position-dependent errors remain after calibration. (`ponytail:` deliberately
> avoiding an RL framework until a simpler correction is proven insufficient.)

---

## 6. Perception / UI grounding — reuse models before training

"Find the login button" → screen coordinates. **You likely don't need to train
anything at first:**

- ⭐ **UGround** (OSU-NLP; Qwen2-VL; open weights) — universal GUI visual grounding,
  SOTA on ScreenSpot-Pro. github.com/OSU-NLP-Group/UGround · huggingface.co/osunlp/UGround
- **OmniParser** (Microsoft) — screenshot → structured elements to feed a general
  VLM (GPT-4V/Claude).
- **SeeClick** — screenshot-only GUI agent + **ScreenSpot** benchmark (**includes
  iOS** screens — relevant to us).
- **OS-Atlas** — foundation action model + 13M-element open grounding corpus (data
  for fine-tuning).
- ⭐ **ZonUI-3B** — lightweight grounding model **trainable on one RTX 4090 with
  ~24K samples** — realistic target when we train our own.

---

## 7. Agent control loop

```
loop:
  frame   = camera.capture()
  screen  = calibrate(frame)              # homography (§5)
  state   = perceive(screen)              # OCR + grounding model (§6)
  action  = plan(command, state)          # intent → next primitive
  xy      = screen_to_gantry(action.tgt)  # calibration transform
  robot.do(action, xy)                    # move/tap/swipe/type (§4)
  if verified(camera.capture(), expected): continue else retry/abort
```

Mirrors `../research/05-ai-agent-architecture-notes.md`; only the action layer is
physical. Every action is **verified** against the next frame.

---

## 8. Command vocabulary

High-level intents expanded into primitive sequences:

| Command | Meaning | Expansion |
|---|---|---|
| `exit` | Leave screen/app | tap back/close, or swipe-up home |
| `enter` | Confirm/submit | tap primary button (Continue/Submit/OK) |
| `login <target>` | Authenticate | focus user → type user → focus pass → type secret (vault) → `enter` |
| `open <app>` | Launch app | home → locate icon → tap |
| `type <text>` | Type on keyboard | per-key tap sequence |
| `tap <label>` | Tap described element | ground `<label>` → tap |

`login` is the flagship command and the reason the credential vault exists.

---

## 9. Credential handling & security (non-negotiable)

- **No secrets in the repo, ever.** `.gitignore` excludes env/keys/vault/datasets.
- Secrets live in a **host-side vault** on HomeLab (macOS Keychain / 1Password CLI /
  `sops`+`age`). Agent requests the specific secret for the specific target at the
  moment of use; **never logs or persists its value.**
- **Scrub training data:** any frame where a secret is visible mid-type is dropped
  or masked before entering a dataset.
- **iOS reality:** Face ID / passkey-only logins can't be driven by a robot; scope
  `login` to credential-typeable flows.

### ML training rig (charter D4)
- **Data-collection app** records `(screen_image, command, action, target, outcome)`;
  `outcome` self-labels from the next-frame state change (§7).
- **Layer A (Phase 2):** off-the-shelf UGround/OmniParser + homography — no training,
  but generates labeled data.
- **Layer B (Phase 3):** fine-tune a small grounding model (ZonUI-3B scale) on our
  own iPhone captures; imitation learning from operator demos.
- **Metrics:** task success rate on a fixed eval battery (ScreenSpot-style),
  taps-to-completion, calibration drift, and **zero secret leaks** (hard gate).

---

## 10. Recommended build path (lazy senior-dev route)

1. **Motion:** OpenBuilds ACRO + **GRBL** + servo-Z pen fork → working
   move/tap/swipe with zero custom firmware.
2. **Bridge:** Python `pyserial` streamer exposing `move/tap/swipe/type`.
3. **Calibration:** steal Tapster's browser calibration page + OpenCV homography.
4. **Perception:** UGround (or OmniParser + a VLM) zero-shot — no training yet.
5. **Agent:** implement the §7 loop with §8 commands; add the vault last (§9).
6. **Only then**, if accuracy/speed/cost demand it, train ZonUI-3B on collected data.

---

## 11. Citations & links

**Robots / firmware to reuse**
- Tapsterbot — https://github.com/tapsterbot/tapsterbot · https://tapster.io · fork https://github.com/pylapp/tapsterbot
- Tappy — https://github.com/merinsTDL/tappy · https://github.com/guntiss/tappy · https://github.com/DeMaCS-UNICAL/tappy-original
- BrainyBot (CV taps phone) — https://github.com/DeMaCS-UNICAL/TappingBot
- Delta-Kinematics-Library — https://github.com/tinkersprojects/Delta-Kinematics-Library

**Motion firmware**
- GRBL — https://github.com/gnea/grbl · FluidNC — https://github.com/bdring/FluidNC
- Grbl_Pen_Servo — https://github.com/bdring/Grbl_Pen_Servo · grbl-servo — https://github.com/vankesteren/grbl-servo · grbl 28BYJ+servo — https://github.com/ArcaEge/grbl-28byj-48-pen-plotter-servo

**Motor / servo libraries**
- AccelStepper — https://www.airspayce.com/mikem/arduino/AccelStepper/
- SpeedyStepper — https://github.com/Stan-Reifel/SpeedyStepper · StepperDriver — https://github.com/laurb9/StepperDriver · DRV8825 — https://github.com/RobTillaart/DRV8825
- ServoEasing — https://github.com/ArminJo/ServoEasing · PCA9685 (Adafruit) — https://learn.adafruit.com/16-channel-pwm-servo-driver · PCA9685_RT — https://github.com/RobTillaart/PCA9685_RT
- A4988 / DRV8825 driver tutorials — https://www.makerguides.com/a4988-stepper-motor-driver-arduino-tutorial/ · https://www.makerguides.com/drv8825-stepper-motor-driver-arduino-tutorial/

**Host G-code control**
- python_to_GRBL — https://github.com/Sam-Freitas/python_to_GRBL · streaming gist — https://gist.github.com/jonkensta/7a69bb386fc31ebf3a4beeba2491ef51
- UGS — https://github.com/winder/Universal-G-Code-Sender · bCNC — https://github.com/vlachoudis/bCNC · gSender — https://github.com/Sienci-Labs/gSender

**Simple deterministic control (Firmata — the Tapster way)**
- pyFirmata guide (control Arduino from a Pi in Python) — https://roboticsbackend.com/control-arduino-with-python-and-pyfirmata-from-raspberry-pi/
- firmatazero (GPIO-Zero-style Firmata) — https://github.com/ollipal/firmatazero
- Firmata protocol examples — https://github.com/McGillBattlebotsClub-org/intro-to-firmata
- clapi-arduino (Pi↔Arduino serial) — https://github.com/tonykolomeytsev/kekmech-clapi-arduino
- Tapster REPL usage (`go(x,y,z)`) — https://github.com/hugs/tapsterbot

**Computer vision**
- Perspective warp / homography — https://thelinuxcode.com/perspective-warp-in-python-with-opencv-homography-four-point-mapping-and-real-time-camera-views/
- OpenCV calib3d — https://docs.opencv.org/4.x/d9/d0c/group__calib3d.html · camera calibration — https://docs.opencv.org/4.x/dc/dbb/tutorial_py_calibration.html
- OpenCV_Position — https://github.com/RaubCamaioni/OpenCV_Position · detecting a smartphone screen — https://forum.opencv.org/t/detecting-a-smartphone-screen/6829
- Trainer app touch capture: MDN Touch events — https://developer.mozilla.org/en-US/docs/Web/API/Touch_events/Using_Touch_Events

**CV-robot reference builds**
- Petri-Dish-Gantry — https://github.com/Shen-Kev/Petri-Dish-Gantry · Delta-Robot-Project (EmguCV) — https://github.com/tunmaker/Delta-Robot-Project
- Pick-and-Place-3-DOF — https://github.com/himadripoddar/Pick-and-Place-3-DOF-Robotic-Arm · Gantry pose estimation — https://github.com/Mowbray-R-V/Gantry_control-pose_estimation

**UI grounding models / benchmarks**
- UGround — https://github.com/OSU-NLP-Group/UGround · https://huggingface.co/osunlp/UGround
- OmniParser — https://arxiv.org/html/2408.00203v1 · SeeClick — https://github.com/njucckevin/SeeClick · OS-Atlas — https://arxiv.org/html/2410.23218v1 · ZonUI-3B — https://github.com/Han1018/ZonUI-3B

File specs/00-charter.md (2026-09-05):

# 00 — Project Charter

**Project:** iPhone Accessibility Robot (`iPhone-Ian`)
**Status:** Research + spec. Nothing built yet.
**Owner:** mchdeore

---

## 1. One-sentence goal

Build a physical robot that drives a **stock, unmodified iPhone** by tapping its
screen, controlled by a vision-based AI agent that responds to high-level
commands (`login`, `enter`, `exit`, …) and pulls any needed secrets from a
host-side vault.

## 2. Decisions set in concrete

These are fixed for now. Everything else is open for iteration.

| # | Decision | Notes |
|---|---|---|
| D1 | **Target is iPhone / iOS only.** | No Android. The Android research is demoted to background. |
| D2 | **Physical actuation** — the robot touches the glass. | No jailbreak, no MDM, no developer provisioning, nothing installed on the phone. Black box. |
| D3 | **Base platform: the Instructables "Screen Tapping Robot" — 3D-printed.** | Design source of truth. A stepper-driven Cartesian XY gantry; 3D-print all printable parts, buy motors cheap. Tappy is demoted to a lessons reference. See `01-hardware.md`. |
| D4 | **An ML training rig / data-collection app is a first-class deliverable.** | We explicitly invest in training the agent to perform well, not just scripting it. See `02-firmware-and-software.md`. |
| D5 | **Command-driven, credential-aware.** | Accepts intents like `login`/`enter`/`exit`; retrieves credentials automatically so the human never hand-types them. |

## 3. Scope boundary vs. HomeLab

- **HomeLab** = the permanent home PC / Linux server + CI/CD. That is where the
  *host* runs — the machine that executes the agent, holds the credential vault,
  and talks to the robot's controller. HomeLab's repo keeps all server/CI-CD
  content.
- **This repo (`iPhone-Ian`)** = everything about making a robot control the
  phone: research, hardware design, the agent, the training rig. It is *built on
  top of* HomeLab but versioned separately.

Rule of thumb: **if it would exist without the robot, it's HomeLab. If it only
exists to drive the phone, it's here.**

## 4. Why physical, on iPhone specifically

A stock iPhone offers no general third-party control surface:

- No ADB equivalent for arbitrary input injection.
- Apple's automation surfaces are constrained: Shortcuts (only app-exposed
  actions), Accessibility (Voice Control / Switch Control / AssistiveTouch),
  XCUITest (needs a paired Mac + developer provisioning), MDM (enterprise
  enrollment). None satisfy "arbitrary, zero-install, on any phone I set it in
  front of."
- Therefore: **touch the glass like a human would.** The capacitive-touch
  physics (`research/02-mechanical-architecture-notes.md`) apply identically to
  iPhone, so that research transfers fully.

*(This is the project's central bet. If the black-box / zero-install constraint
were relaxed, a Mac + XCUITest path would be far cheaper — worth a conscious
re-check before committing hardware money. Labeled as the key assumption to
validate.)*

## 5. iOS-specific constraints to design around

- **Biometrics for login.** Many iOS logins now prefer Face ID / passkeys /
  iCloud Keychain autofill — a robot can't present a face or fingerprint. So
  "`login`" means: **type username + password into fields** for sites/apps that
  still accept typed credentials, or trigger an autofill flow the human then
  approves. Passkey-only logins are out of scope for the robot.
- **No accessibility tree.** Because the phone is a black box, the agent cannot
  read iOS's view hierarchy. Perception must be **camera-based** (an overhead
  camera) + OCR / vision grounding. This makes calibration (camera px → screen
  coord → gantry coord) the crux — consistent with the Tappy team's finding that
  *calibration, not mechanical precision, is the bottleneck*.
- **Text entry** happens by tapping the on-screen keyboard, key by key (slow but
  universal), unless a paste/autofill shortcut is available.

## 6. Security (non-negotiable)

Credential handling is the highest-risk part of this project.

- **No secrets in this repo. Ever.** `.gitignore` excludes `.env`, `secrets/`,
  keys, and vault files.
- Credentials live in a **real secret store on the HomeLab host** (candidates:
  macOS Keychain, 1Password CLI, or `age`/`sops`-encrypted files). The agent
  requests a secret at the moment it's needed and never logs its value.
- The robot **types** secrets onto the phone; secrets should not be persisted in
  action logs, screenshots, or training data. Screenshots captured for training
  must be scrubbed of any frame where a secret is visible in a field.
- Treat the credential-retrieval command path as a trust boundary: validate
  which secret is being requested for which target before releasing it.

## 7. Roadmap (phased)

**Phase 0 — Research close-out (here, now).**
- [x] ~~Dedicated search for a **Cartesian XY-gantry** reference build~~ — **FOUND:**
  the Instructables "Screen Tapping Robot" (now the design source of truth,
  `01-hardware.md`). Remaining: extract its Y-axis/Z/controller/BOM details.
- [ ] Confirm the iOS control constraints above (biometrics/autofill behavior under robot control).
- [ ] Decide: is the black-box constraint hard? (the §4 assumption check).

**Phase 1 — Mechanical prototype.**
- [ ] 3D-print and build the "Screen Tapping Robot" (design source of truth); add the grounding path (known Tappy gotcha).
- [ ] Rig a fixed iPhone mount + overhead camera.
- [ ] Nail the calibration routine (camera → screen → gantry).

**Phase 2 — Perception + control loop.**
- [ ] Off-the-shelf VLM/OCR grounding → tap coordinates (no training yet).
- [ ] Implement the `tap`/`swipe`/`type` primitives against the gantry.

**Phase 3 — Training rig.**
- [ ] Data-collection app: record (screen image, command, action, outcome).
- [ ] Fine-tune / evaluate a grounding model; close the loop with success metrics.

**Phase 4 — Commands + credentials.**
- [ ] Intent vocabulary (`login`/`enter`/`exit`/…) → action sequences.
- [ ] Vault integration with the security rules in §6.

## 8. Open questions

- Repo/brand name — `iPhone-Ian` is a placeholder.
- Which specific iPhone model(s) are the first targets (screen size/curvature
  affects the mount and calibration)?
- Host↔controller link: USB serial to a microcontroller (GRBL-style) vs. a
  Raspberry Pi driving steppers directly?

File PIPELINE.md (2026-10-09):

# iPhone-Ian — Detailed Pipeline

Step-by-step breakdown of `PLAN.md`, wired into Marc's `research/` vault and the hardware design in `aria/hardware-concept-v2.md`. No hard dates; order and gates matter, not the calendar.

Legend: **[A]** Aria / hardware · **[M]** Marc / software+model · **[S]** shared.

---

## Stage 2 — Design (current)

- [A] Base-plate CAD, slotted holes → JLCCNC quote.
- [A] Printable parts: toolhead + lever + stylus sleeve, end blocks, idler posts, motor clamps, phone slots, cable guides, controller box.
- [A] Wiring plan from the MKS DLC32 / TMC2209 docs: servo pin, power input, motor + endstop pinout — so "confirm on arrival" becomes "known now."
- [A] FluidNC `config.yaml` draft: `noradio` build, CoreXY kinematics, RC-servo Z, soft limits. → backs `research/Robotics/Gantry — FluidNC Control Interface`.
- [S] Lock the robot interface: `move(x,y) / tap() / down() / up() / home()` over USB serial, mm in the machine frame (concept doc §3.1). Marc codes against a **fake robot** stub implementing this now.
- [S] Finalize BOM, work-sourcing, split, place the order (`BOM.md`).

**Open Qs to close on a call:** cases vs bare phones (slot width + spring travel); which offline app is the reference target.

---

## Stage 3 — Build & bring-up ("get it moving") · [A] lead

1. Print all parts; heat-set inserts in.
2. Assemble frame, rails, CoreXY belts; motor pulleys hub-up; idlers clamped top+bottom.
3. Flash FluidNC `noradio`; load `config.yaml`.
4. Wire motors, endstops, servo (via Mini560 PRO 5 V), 24 V in.
5. Home (`$H`); square the axes; set soft limits = phone-row rectangle.
6. Mount the grounded spring-stylus; **ground wire to controller GND** (mandatory for PCAP — `research/Robotics/Gantry — Capacitive Touch Physics`).
7. Tune TMC2209 StealthChop for quiet; set feed/accel.

**Gate:** a hand-sent `move`+`tap` lands a registered touch on the phone. First tap on 1 phone.

---

## Stage 4 — Simple test app · [M] lead, [A] calibration rig

Backs `research/System Design — Bare-Minimum iPhone Setup (MVP)` and `— Drag, Tap and Verify Primitives`.

1. [M] `capture.py` — pull frames from the phone (USB screen capture to the PC).
2. [S] `calib.py` — tap known points, fit screen-px → machine-mm homography. With screen capture the pixels are exact (`research/Robotics/Rig — Camera-to-Screen Calibration`).
3. [M] `robot.py` — the interface over serial (soft limits = screen rect).
4. [M] minimal harness: show a target, command a tap/drag, verify from the next frame; log every action as JSONL.
5. [A] printed calibration fixture + repeatability check (tap a grid, measure error).

**Gate:** robot hits pointed-to targets ≥ ~19/20 across the screen; drags move reliably; every action logged.

---

## Stage 5 — Train the model (local, on Marc's PC) · [M] lead

Compute: multi-year gaming CPU, 32 GB DDR4, **GTX 1080 = 8 GB VRAM**, M.2 SSD. The 8 GB VRAM is the hard limit.

- [M] Model choice must fit 8 GB. QLoRA/4-bit on a **small** VLM, or a compact detector (YOLO) for UI elements, offloading to RAM/SSD as needed. Marc's `research/Machine Learning — QLoRA Fine-Tuning a Small VLM on 12 GB` assumes 12 GB — **re-scope for 8 GB** (smaller base, lower res, gradient checkpointing, or train UI detection only and keep reasoning on a prompted model).
- [M] Perception: template-match or a small YOLO on captured frames (`research/System Design — Reading Cards from the Screen`, `research/.../YOLO`).
- [M] Data: capture runs from Stage 4; synthetic + real frames (`research/.../YOLO — Efficient Dataset Recipe`, `— Synthetic Data`).
- [S] **Natural interaction quality** = taps/drags with realistic timing and smooth motion, so actions are reliable and non-jerky. This is a *quality/robustness* goal (and good robotics), **not** a bot-detection-evasion goal — see guardrails. Physical side (motion smoothing, dwell/hold timing, touch telemetry) is [A]; policy side is [M].
- [M] Loop: screen → perceive → decide → plan → act → verify, state machine as source of truth (`research/System Design — Card-Playing Gantry Rig Architecture`, `— Reliability, Error Recovery`).

**Gate:** the model drives the robot through the Stage-4 app unattended.

---

## Stage 6 — Teach it poker (parallel with Stage 5) · [S], game theory [M]

Backs `research/Math/Game Theory — *` (CFR, GTO vs exploitative, Poker AI milestones).

- Rules/state engine for the chosen poker variant.
- Decision engine: CFR / counterfactual regret for the computer opponent; betting conventions, hand strength, position.
- Validate in pure simulation before any screen.

**Gate:** decision engine plays correctly in sim (beats a greedy baseline by a clear margin).

---

## Stage 7 — Offline poker test · [S]

- Install an **offline** poker game on the test phone (no real money, no accounts).
- Run trained model (5) + engine (6) + robot through full games.
- Measure: win rate vs the AI, action accuracy, taps/hand, failures, recovery.

**Gate:** completes games unattended; we have real performance numbers to optimize against.

---

## Stage 8 — Optimize · [S]

- [M] Model: errors from Stage 7 → retrain/prompt-tune; speed vs accuracy on the 1080.
- [A] Motion: faster safe feed/accel, quieter, tighter calibration; 2nd-phone throughput.
- [S] Reliability: RECOVER ladder, timeouts, SAFE_STOP, hours-long unattended runs (`research/System Design — Reliability`).

**Gate:** accuracy, speed, and stability are good enough that we'd trust it on the real task.

---

## Stage 9 — Commissioned app · [S]

Only after Stage 8. Test the authorized target app **within its ToS and the engagement agreement**.

- Confirm the authorization/ToS scope in writing before running it.
- Carry all guardrails (below). Keep runs logged.
- Detection stacks are *understood* from `research/Cybersecurity` (mapping only); we do not attempt to defeat them.

**Gate:** the agreed test runs and is reported.

---

## Stage 10 — Scale & refine (ongoing) · [A] hardware

- 2nd phone slot live; then more phones (longer rails, set `N_PHONES`).
- v3: bent-aluminium tray/bridge, quieter drive, slimmer.
- Drawer enclosure + 24/7 charging/thermal check.

---

## Guardrails (every stage)
- Authorized/commissioned and offline/play-money targets only. **No real-money multiplayer poker.**
- **No detection-evasion work** (anti-bot, geofencing, biometric/identity spoofing). Detection is mapped to understand risk, never bypassed. "Human-like" = interaction quality, not disguise.
- Never train against a judge on apps that move money or send messages (`research/.../RL — Rewards and Success Detection`).
- Test phones: no real credentials/payments/messaging; notifications off; dedicated test Apple ID.
- Controller USB-only, Wi-Fi off (`noradio`); remote access via the host only.

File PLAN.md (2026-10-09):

# iPhone-Ian — Project Plan (big steps)

How the project matures, no hard dates. Two tracks run in parallel — **hardware** (Aria) and **software/model** (Marc) — and merge once the robot moves. Detailed breakdown in `PIPELINE.md`.

**What it is:** a CoreXY gantry that taps a real iPhone's screen, driven by a local vision model running on Marc's PC. Scope is our own and offline/play-money apps, plus a commissioned app we are authorized to test under its ToS and our engagement agreement.

---

## The stages

**1. Define** — purpose, requirements, scope, ToS/authorization boundary.
*Hardware requirements locked. Concept scope mostly set.*

**2. Design** — hardware drawings + BOM; software architecture; the fixed interface between them (`move / tap / down / up / home` over USB).
**← we are here.** Hardware ~90% (base plate + printed parts left). BOM done.

**3. Build & bring-up — "get it moving."** Order, print, assemble. The robot homes, moves, and taps on command. No intelligence yet.
*Gate: a manual command produces a registered tap on the phone.*

**4. Simple test app** — a minimal app/harness to exercise the robot's basic abilities (tap a target, drag, confirm it worked) and to start logging runs.
*Gate: the robot reliably hits targets we point it at, end to end.*

**5. Train the model** — stand up the local vision model on Marc's PC and tune it to read the screen and act naturally and reliably (human-like interaction quality). Runs against the test app.
*Gate: the model drives the robot through the test app on its own.*

**6. Teach it poker (parallel to 5)** — game-theory research: hands, plays, betting conventions, decision engine.
*Gate: a decision engine that plays correctly in simulation.*

**7. Offline poker test** — run the trained model + engine on an **offline** poker game. First look at real performance.
*Gate: it completes games unattended and we can measure how well it plays.*

**8. Optimize** — tune model, motion, and reliability against what we saw in stage 7. Error recovery, speed, unattended runtime.
*Gate: we're happy with accuracy, speed, and stability.*

**9. Commissioned app** — only once optimized: test the authorized target app, within its ToS and the engagement agreement.
*Gate: runs the agreed test.*

**10. Scale & refine (ongoing)** — 2nd phone slot and beyond; quieter/slimmer v3 hardware; the drawer enclosure.

---

## Ownership
- **Aria:** all hardware — CAD, BOM, sourcing, assembly, bring-up, calibration rig; plus the physical/actuation side of "natural interaction" (motion smoothness, timing, touch telemetry).
- **Marc:** software, the local model, training/optimization, and the poker decision engine. He owns the compute tuning on the 1080.
- **Shared:** the move/tap interface, the test app spec, scope and ToS guardrails.

## Guardrails (carried through every stage)
- Authorized/commissioned and offline/play-money targets only. No real-money multiplayer poker.
- No work on evading bot detection, geofencing, or identity/biometric checks — detection is mapped for understanding only (Marc's `research/Cybersecurity`), never defeated.
- Test phones carry no real credentials, payments, or messaging apps.
- Controller runs USB-only, Wi-Fi off (FluidNC `noradio` build); all remote access goes through the host.

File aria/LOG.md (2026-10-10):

# Aria's log (hardware)

Newest first.

## 2026-10-10: base plate drafted

`cad/base_plate.py` builds the JLCCNC plate from the layout's dimensions (nothing hard-coded twice). Outputs `base_plate.dxf` (laser profile), `base_plate.step` (regenerate; gitignored) and `base_plate_preview.svg` (plate + footprints).

- **340.6 × 320 × 3 mm**, R5 corners, 40 M3 holes. The script checks edge distance, hole-to-hole metal and clashes with every footprint: none, closest gap 10.6 mm.
- **Slots (±2 mm):**
  - rail risers ×8, slotted along Y to set the rails parallel
  - motor cradles ×8, along X, which doubles as belt tension
  - corner idler bolts ×2 and their bracket anchors ×4, along X so the bracket slides with the bolt
  - phone trays ×8, along X
- **Round holes:** feet ×6, and the camera mast ×4 at the back edge (+Y), reserved for now.
- **Riser screws** sit at x = ±40/±100, midway between the MGN9 rail's own holes. Drill the risers using the plate as a template.

Constraints that come with it:
- **Button-head screws under the plate.** Feet are 3 mm and socket heads are 3 mm.
- **The controller doesn't fit on the plate.** The toolhead sweeps the free area at ~20 mm and the DLC32 with drivers is ~30 mm tall, so it lives in a separate printed box beside the machine.
- **Motors are held on two sides only** (−X and inner Y). The +X and outer sides sit ~4 mm from the plate edge.
- The printed cradle, corner bracket and trays must be designed to these hole positions.

**Next:** check the STEP in Onshape, then get the JLCCNC quote.

## 2026-10-08 (later): AliExpress order placed

**Ordered (~C$381 tax-in, after dropping the inserts + screw box).** Paid by Aria; split with Marc.

Bought (21 lines): MKS DLC32 V2.1 (board only), TMC2209 ×4, 2× NEMA17 17HE08-1004S, MG90S ×2 (180°), 24 V 3 A PSU, Mini560 PRO 5 V, endstops ×3, **MGN9H 230 mm ×3**, 2020V extrusion 240 mm, 20T pulleys ×2 packs (1 spare pair), M3 nyloc nuts, M3×5 0.5 mm shim washers, brass tube OD5 300 mm, springs 0.5 mm 7 mm-OD ×20 mm, 26 AWG wire, servo extension, DC jack ×2, **GT2 6 mm PU steel-core belt 5 m** (upgraded from rubber — original sold out), **idlers 7 toothed + 5 smooth** (Mellow, bearing-type; original listing sold out), M3 T-nuts for 2020.

Substitutions vs BOM: belt → PU steel-core; idlers → Mellow bearing (pricier but quieter/stiffer); both because the §5 listings went sold-out/no-ship to CA.

**Reused from Olyntia's Amazon set (not re-bought):** M3 heat-set inserts, initial M3 screws.

Still to buy later:
- **Base plate** — JLCCNC, after the plate CAD.
- **M3×50 idler-axle bolts + exact-length screw top-up** — after printed parts are designed.
- **Amazon: stylus tips + 6061 rail bar** — confirm these went in (rail bar is the ~3-week long-lead item).

## 2026-10-08: plan, pipeline, BOM; prices rechecked

- Read Marc's merged `research/` vault. Hardware v2 is now the "current design" on `main`.
- Added three shared root docs: `PLAN.md` (big steps), `PIPELINE.md` (detailed, wired to Marc's research), `BOM.md` (orderable parts list).
- **Workflow change: we work on `main` directly now — no owner branches.** Equal partners.
- FluidNC Wi-Fi question answered: use the `noradio` build (no radios compiled in).
- Rechecked prices into Waterloo N2J:
  - Amazon stylus tips C$8.49 (only 6 in stock), free ship over $35.
  - Amazon rail bar C$26.64 **+ C$5.54 ship**, slow (Oct 30–Nov 20) — order early.
  - AliExpress ships free to Canada, HST added at checkout. Per-item prices are promo/variant/account-dependent, so cent-exact verification isn't meaningful; §5 baseline holds, confirmed at my own checkout.
  - **All-in estimate ~C$370 (tax in), ~C$185 each** before work-sourcing. Full breakdown in `BOM.md`.

## 2026-10-02 (later): until the next sync

- **Next sync: Wednesday 2026-10-07.**
- Both of us are doing research before then.
- **Screen input is undecided and on hold:** webcam vs screen capture.
- **Hardware impact:** a fixed webcam over 2 phones needs ~14 cm above the glass, so the machine grows from ~5 cm to ~16 cm tall.
  The alternative is a small camera riding on the gantry. Until this is decided, the hardware stays camera-agnostic: reserve mount points at the back edge for a camera mast.

## 2026-10-02: call with Marc

**Decisions:**
- **2-phone capacity, 1 phone to start testing.** The CAD is now 2 phones (`N_PHONES = 2`): ~34 × 32 × 5.0 cm.
- **Budget:** split the ~C$325 (+tax) build between us.
- **Repo:** split into `aria/` (hardware) and `marc/` (software and his v1 CAD). Shared docs stay at the top.
- **Parts list:** Marc is OK with it. He'll check what he can get through work; the sourcing columns in `hardware-concept-v2.md` §5 are for that.
- Both of us have 3D printers and essentially free filament.

**Marc's action items (from his notes):**
- what from the parts list he can get from work
- how to code and train the OCR and the reinforcement loop
- an overview of the parameters each side exposes
- a high-level functional diagram
- organize the research (game theory, ML)
- the end goal: a real architectural design and final physical design
- list what we each have at work and home
- nuke the database

**Aria's action items:**
- parts I can get from work
- base plate CAD with slotted holes, then a JLCCNC quote
- printable parts

## 2026-10-01: v2 proposal (supersedes Marc's v1 rod gantry)

Hardware is now owned by Aria, software by Marc. The full write-up is in **`hardware-concept-v2.md`**.

- **Requirements:**
  - up to 4 iPhones of any model
  - screen inputs only (tap, long-press, swipe)
  - typing at 2–3 taps/s
  - quiet, drawer-height
  - mostly 3D printed, low cost
- **Design:**
  - CoreXY gantry on MGN9 rails over a row of 4 phone slots
  - MKS DLC32 board running FluidNC
  - MG90S servo tap with a spring-loaded, grounded stylus
  - 3 mm aluminium base (JLCCNC)
  - ~53 × 32 × 5.0 cm
- **No overhead camera** (it would need ~28 cm of height). The proposal is screen capture over USB/AirPlay; **Marc to confirm**.
- **Model:** `cad/v2_0_layout.py`. It models both belt paths, idlers bolted top and bottom, and motor clamps. Checks: every
  screen corner is reachable with the carriages on their rails, and nothing collides. Run it from `cad/` with the repo `.venv`.
- **Parts:** verified AliExpress / Amazon.ca links and prices are in doc §5. About C$246 on AliExpress, ~C$340–375 for the
  whole build.
- **Retired:** the v1 rod/oilite gantry parts (1, 3, 4) and `0_assembly_preview.py`, because the heights didn't fit and
  the one-sided Y drive would jam. See doc §4.
- **Next:**
  - base plate CAD with slotted holes, then a JLCCNC quote
  - real printable parts (toolhead, end blocks, idler posts, motor clamps, phone slots)
  - Marc's answers to the doc §7 questions

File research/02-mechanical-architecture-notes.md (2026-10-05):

---
tags: [capacitive, PCAP, grounding, gantry, delta, stylus, calibration, mechanical]
status: answered
date: 2026-10-05
related:
  - "[[01-prior-art-notes]]"
  - "[[07-ios-control-constraints]]"
  - "[[08-xy-gantry-builds]]"
---

# Mechanical architecture: touch physics, gantry vs delta, grounding

## Question

How does capacitive touch actually work, and what does that mean for our robot's mechanical design? What architecture options exist (delta vs gantry), and what gotchas do we need to design around?

## Key findings

### How capacitive touch works

Modern phones use projected capacitive (PCAP) mutual-capacitance sensing: an ITO electrode grid under the cover glass. Each intersection is a small capacitor. A grounded conductive object nearby draws away local field → the controller detects the capacitance dip → computes coordinate.

**Grounding is the critical variable.** A floating, ungrounded conductive tip often registers weakly or not at all. The human body provides a large earth-referenced capacitance — a robot stylus must replicate this. TestDevLab Tappy empirically confirmed: touches didn't register until they added a ground wire from Arduino to stylus pen. `[Community/empirical]`

Detection is capacitive, not pressure-based. Mechanical force is irrelevant to touch registration — only consistent contact geometry matters.

Sources: https://www.densitron.com/company/news/projected-capacitive-touch-sensor · https://software-dl.ti.com/msp430/msp430_public_sw/mcu/msp430/CapTIvate_Design_Center/1_83_00_08/exports/docs/users_guide/html/CapTIvate_Technology_Guide_html/markdo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

### Architecture comparison

| Architecture | Cost | Tap | Swipe | Multi-touch | Complexity | Precision |
|---|---|---|---|---|---|---|
| Single solenoid/servo tapper | $10–40 | Yes | No | No | Lowest | Fixed point only |
| Delta-robot (Tappy) | ~$80 | Yes | Yes | No | Medium (inverse kinematics) | Good, but joint slop |
| Cartesian XY gantry (our target) | ~$100–300 | Yes | Yes | Yes (2+ effectors) | Low (linear X/Y, no kinematics) | Best (sub-mm) |
| Commercial multi-effector (MATT) | $1,000+ | Yes | Yes | Yes (true) | N/A (buy, don't build) | Industrial |

**Why Cartesian beats delta for us:**
- No inverse kinematics required — X/Y map directly to screen after affine calibration.
- Stiffer than delta servos → less positioning slop → better calibration stability.
- Scales to two effectors if we ever want multi-touch.
- GRBL firmware directly supports Cartesian — zero custom firmware.

TestDevLab explicitly considered and abandoned a CNC gantry for Tappy: "It was difficult to adapt CNC's configuration and software for touchscreen testing." They went delta, but for general phone testing (not our fixed-mount use case).

### Coordinate accuracy

Gantry/stepper designs hit sub-millimeter mechanical accuracy. Android's minimum touch target is 48dp (several mm), so mechanical precision is rarely the limiting factor. **Calibration accuracy (rig coordinate frame → screen coordinate frame) is the actual bottleneck.** Tappy built a dedicated browser-based calibration page — not relying on measured/assumed geometry.

### Does modern phone hardware make this harder?

- Thinner glass **helps** (less capacitive attenuation).
- Edge-to-edge/curved screens are a geometric problem (stylus calibrated for flat center may not contact near curved edges where surface normal changes). Industry trend 2025–2026 is back toward flat panels — helps us.
- Modern electrode sensitivity (glove-touch/stylus support) makes reliable triggering **easier**, not harder.

### Screen protector interference

Thin, properly-applied protectors don't meaningfully block capacitive detection. Thick/air-gapped protectors add attenuation and could push a marginal actuator (weak grounding, borderline tip conductivity) into unreliable territory. Test directly once a prototype exists.

### Stylus tip materials

- **Conductive silicone** — best. Longest wear life, consistent capacitance. `[Community]`
- **Carbon-fiber composite** — good. Durable, less compliant. Less likely to deform under repeated servo strikes.
- **Conductive foam** — budget. Works but wears out. Standard for DIY builds.
- **Metal/coin** — works but risks scratching screen.
- **Battery negative pole** — crude but functional. Used in one Instructables build.

Wipe tips weekly with isopropyl alcohol. Ask suppliers for cycle-life data (100,000+ actuations target).

### Grounding: universal pattern

Connect GND of microcontroller (Arduino) to conductive stylus tip via wire. This creates the capacitive path that a human body normally provides. No one has documented a better approach than the ground wire. This is mandatory — not optional.

### No phone modification required

Every physical actuator method treats the phone as an opaque black box. No Developer Options, no USB debugging, no accessibility service, no root. The only "install" is Tappy's optional browser-based calibration webpage (no persistent footprint). This is the core value proposition over every software method.

## Sources

- https://www.densitron.com/company/news/projected-capacitive-touch-sensor
- https://software-dl.ti.com/msp430/msp430_public_sw/mcu/msp430/CapTIvate_Design_Center/1_83_00_08/exports/docs/users_guide/html/CapTIvate_Technology_Guide_html/markdo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
- https://www.testdevlab.com/blog/how-we-built-a-robot-for-automated-manual-mobile-testing
- https://www.allpcb.com/allelectrohub/how-capacitive-styluses-work
- https://www.howtogeek.com/835769/active-vs-passive-styluses-all-the-standards-explained
- https://electronics.alibaba.com/buyingguides/robot-stylus-touch-pen-guide-what-actually-matters — Robot stylus guide (Aug 2026), conductive tip materials, grounding

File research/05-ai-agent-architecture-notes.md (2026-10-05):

---
tags: [agent, VLM, perception, planning, action-loop, droidrun]
status: answered
date: 2026-10-05
related:
  - "[[01-prior-art-notes]]"
  - "[[06-vlm-gui-agent-survey]]"
  - "[[07-ios-control-constraints]]"
---

# AI agent architecture — perception→planning→action loop

## Question

How should the perception→planning→action loop work for a vision-based AI agent driving a physical iPhone-tapping robot? What's the closest existing precedent?

## Key findings

### droidrun / mobilerun — closest existing software analog

Open-source framework wrapping Accessibility Service + ADB with an LLM-agent control loop. Installs on-device "Portal" app exposing UI tree + screenshots to host-side agent. Agent reasons over observed state (vision + structured tree) and issues taps/swipes/text/app-launch. `[Documented]` https://github.com/droidrun/mobilerun

Architecturally a perception→planning→action loop in software-only form. The perception and planning halves (VLM/tree-grounding + action planning) are largely reusable — regardless of whether action is `dispatchGesture` or a physical stylus moving to XY.

### Architecture for our physical agent

See full survey in [[06-vlm-gui-agent-survey]]. Summary:

```
Camera photo of iPhone screen
        │
        ▼
  [Perception] — UGround / OmniParser (Phase 2) → ZonUI-3B fine-tuned (Phase 3)
        │  bounding boxes + element descriptions
        ▼
  [Planning] — VLM (GPT-4V / Claude / Gemini) reasons over UI state
        │  "Tap the login button" → action: tap(x=342, y=518)
        ▼
  [Action] — screen coordinate → gantry coordinate → G-code → tap
        │
        ▼
  [Verification] — next camera frame → did it work? → retry or continue
```

**Perception and planning are separate concerns.** Perception benefits from fine-tuning on our domain (iPhone camera photos). Planning works fine with off-the-shelf VLMs.

### Key references (full details in [[06-vlm-gui-agent-survey]])

- Mobile-Agent v3.5 / GUI-Owl-1.5 — 56.5 OSWorld, multi-agent architecture
- OS-Atlas — open-source GUI grounding foundation model
- ZonUI-3B — our fine-tuning target (3B params, single RTX 4090)
- GUI-Primitives — VLMs understand instructions but can't locate precisely (60-92% miss)

## Open questions / follow-ups

- What's the retry/error-recovery strategy when a tap misses?
- How do we handle dynamic content (loading spinners, animations, popups)?
- Sequential navigation RL — only after perception + calibration are solid (per existing note in `specs/02-firmware-and-software.md` §5.1).

## Sources

- https://github.com/droidrun/mobilerun
- See [[06-vlm-gui-agent-survey]] for full VLM/grounding sources

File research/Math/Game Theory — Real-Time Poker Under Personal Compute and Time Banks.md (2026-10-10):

---
type: research
status: answered
author: marc
date: 2026-10-10
tags: [machine-learning, math, game-theory, poker, cfr, real-time, subgame-solving, abstraction, open-spiel]
---

# Game Theory — Real-Time Poker Under Personal Compute and Time Banks

**TL;DR**
- Full no-limit hold'em equilibrium on a laptop **in every spot** is impossible. Winning pattern from superhuman AI: **offline blueprint** + **small subgame solve only where it matters**, under a **hard millisecond budget**.
- On a **personal machine** (one GPU / 8–16 CPU cores), treat decisions as **anytime algorithms**: return the best action seen so far when the timer fires.
- **Scope:** play-money tables, **vs-the-computer** apps, OpenSpiel simulators, and our **gantry rig** test games — not advice for beating real-money multiplayer ([[System Design — Related Work - Robots and Bots that Play Games]]). Operators ban RTA/solvers on money tables; detection is in [[Poker Platforms — RTA Bot and Solver Detection]].

**Builds on:** [[Game Theory — Counterfactual Regret Minimization (CFR)]], [[Game Theory — Poker AI Milestones (Cepheus to Pluribus)]], [[Game Theory — GTO vs Exploitative Play (Poker and Markets)]], [[System Design — Game State and Decision Engines for Card Games]].

---

## 1. What “limited time” actually means

| Context | Typical budget | What fits |
|---|---|---|
| Online cash / MTT (human UI) | **~7–15 s** pre-action clock; **time bank** ~30–90 s per session/hand (site-dependent) | Shallow search + lookup; not full-tree CFR |
| Play-money / vs CPU (our rig) | **2–5 s** per move if gantry-bound ([[System Design — Card-Playing Gantry Rig Architecture]]) | Overlap **solver with robot motion** |
| Offline study | Hours | Blueprint training, abstraction tuning |
| OpenSpiel Kuhn/Leduc | Unlimited | CFR correctness checks ([[Game Theory — Counterfactual Regret Minimization (CFR)]]) |

**Rule:** define `deadline_ms` before coding. Every solver must support **interrupt and return best-so-far**.

---

## 2. Why brute-force CFR on NLHE fails locally

- Abstracted heads-up no-limit hold'em still has **billions+** information sets. Vanilla CFR needs many iterations × large tree.
- Cepheus: **4,800 CPUs × 68 days** for **limit** hold'em [1]. Pluribus: **12,400 core-hours** for 6-max with heavy abstraction [2].
- Commercial solvers (Pio, GTO+, etc.) precompute **hours overnight** for one spot tree — that is the realistic **personal-machine** workload: **batch offline, query online**.

---

## 3. The workable stack (blueprint + bounded search)

Same pattern as Libratus / Pluribus / depth-limited solving [3][4]:

```
OFFLINE (night job, personal PC)
  ├── Abstraction: card buckets, bet-size menu (e.g. 33/75/125% pot)
  ├── MCCFR / CFR+ → blueprint strategy file (compressed)
  └── Optional: small value net (ReBeL-style) for leaf evaluation

ONLINE (each decision, ≤ deadline_ms)
  ├── Parse hand → abstract state + opponent range estimate
  ├── If river or near-terminal → endgame solve (exact-ish on small tree)
  ├── Else if time remains → depth-limited subgame solve from current node
  └── Else → sample action from blueprint (or argmax if exploit mode)
```

### 3.1 Abstraction (do this first)

- **Card bucketing:** EHS, hand strength, board texture → 10–200 buckets per street (not 1,326 combos live).
- **Action abstraction:** 2–4 bet sizes + check/call/fold. More sizes = bigger tree = slower.
- **Tradeoff:** coarse abstraction → fast but **exploitability** in weird sizes; fine abstraction → slow.

### 3.2 Where to spend live compute

| Street / spot | Personal-machine priority |
|---|---|
| **Preflop** | **Zero live solve.** Preflop charts / push-fold tables (ICM for MTT). O(1) lookup. |
| **Flop** | Blueprint only unless heads-up and shallow stacks |
| **Turn** | Subgame solve if `deadline_ms > 2000` and pot large |
| **River** | **Best ROI for live solve** — ranges narrowed, tree smallest |
| **Short-stack / jam nodes** | Precomputed Nash push/fold (≤20 BB) |

### 3.3 Anytime algorithms

- **Depth-limited solving:** expand tree to depth d, evaluate leaves with blueprint or net [3].
- **Iterative deepening:** each CFR iteration improves; stop at deadline.
- **Monte Carlo CFR online:** sample trajectories until timer — high variance but bounded time.

### 3.4 Exploitation under budget ([[Game Theory — GTO vs Exploitative Play (Poker and Markets)]])

- **Default:** blueprint ≈ GTO-ish baseline.
- **Exploit:** only when stat evidence exists (~200+ hands on tendency [5]) → **node lock** opponent freq in a *small* re-solve. Re-solve is smaller tree → fits laptop **if** locked nodes are few.
- **Risk:** wrong lock → worse than blueprint. Fall back to blueprint when sample thin.

---

## 4. ML on a personal GPU (optional layer)

| Approach | Train cost | Inference | Role |
|---|---|---|---|
| **Deep CFR / single net policy** | High; needs self-play data | **<50 ms** | Action picker when no time to search |
| **Value net on leaves** | Medium | **<10 ms** per leaf | Replaces blueprint eval in subgame solve |
| **Behavior clone human/solver** | Low if logs exist | **<5 ms** | Baseline for rig; not equilibrium |
| **Leduc/Kuhn in OpenSpiel** | Minutes | Trivial | Unit tests for CFR code |

**Practical order:** (1) CFR on Leduc in OpenSpiel, (2) blueprint + river solve, (3) net only if still missing deadline.

ReBeL shows RL + search can work with **less domain hand-crafting** [6] — but training is still **not** “install and play”; it is a research pipeline.

---

## 5. Latency budget for **our** phone + gantry loop

From [[System Design — Card-Playing Gantry Rig Architecture]]:

| Stage | Typical ms |
|---|---|
| Capture + perceive cards | 70–250 |
| Build `GameState` | 1–10 |
| **Decide (this note)** | **100–3000** (target) |
| Plan + act (gantry) | 1000–3000 |
| Verify | 50–150 |

**Overlap:** start deciding **move N+1** while gantry executes move N. Effective think time can be **gantry-limited**, not CPU-limited, for turn-based apps.

**Implication:** vs-computer poker on the rig should use **preflop chart + blueprint sample** almost always; reserve subgame solve for river in big pots only.

---

## 6. Implementation checklist (repo-friendly)

1. **OpenSpiel** Leduc poker: CFR+ until exploitability < 0.05 bb/hand; log time vs iterations.
2. **Abstract NLHE toy** (3 bet sizes, 5 buckets): offline MCCFR → `.bin` blueprint.
3. **Online wrapper:** `choose_action(state, deadline_ms)` → anytime CFR or lookup.
4. **Metrics:** exploitability (offline), **decision latency p95**, EV vs baseline bot (online sim).
5. Wire into [[System Design — Game State and Decision Engines for Card Games]] `legal_moves()` → `Move`.

---

## 7. What this does *not* solve

- **6-max multiplayer:** no Nash guarantee; blueprint from self-play is heuristic ([[Game Theory — Poker AI Milestones (Cepheus to Pluribus)]]).
- **Real-money site terms:** using this **during** live money play is RTA/bot territory → bans ([[Poker Platforms — RTA Bot and Solver Detection]]).
- **Opponent modeling latency:** good range updates need hand history; our rig may not have HUD — keep opponent as **population blueprint** unless logging many hands.

---

## Sources

1. [Bowling et al. — Heads-up limit hold'em is solved (Science 2015)](https://webdocs.cs.ualberta.ca/~bowling/publications/b2hd-15science.html) `[Benchmark]`
2. [Brown & Sandholm — Superhuman AI for multiplayer poker (Science 2019)](https://science.org/doi/10.1126/science.aay2400) · [Pluribus compute discussion](https://www.theregister.com/2019/07/12/pluribus_ai_poker_human_pros) `[Benchmark]`
3. [Brown, Sandholm & Amos — Depth-Limited Solving (arXiv 1805.08195)](https://arxiv.org/pdf/1805.08195) `[Benchmark]`
4. [Moravčík et al. — DeepStack (Science 2017)](https://science.org/doi/10.1126/science.aam6968) `[Benchmark]`
5. [GTO vs exploitative sample discipline (community coaching norm)](https://www.deucescracked.com/blog/gto-vs-exploitative-small-stakes-online-poker-2026) `[Community]`
6. [Brown et al. — ReBeL (NeurIPS 2020)](https://arxiv.org/pdf/2007.13544) `[Benchmark]`
7. [OpenSpiel](https://github.com/google-deepmind/open_spiel) — Leduc/CFR reference implementations `[Documented]`

## Related

- **Summary:** [[State of — Math]] · [[State of — Machine Learning]] · [[State of — System Design]]

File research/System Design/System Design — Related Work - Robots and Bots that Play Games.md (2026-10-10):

---
type: research
status: answered
author: marc
date: 2026-10-07
tags: [system-design, robotics, cybersecurity, prior-art, game-bots, poker]
---

# System Design — Related Work: Robots and Bots that Play Games

**TL;DR**
- Three neighbouring fields: **(1) physical device-testing robots** (Tapster), **(2) software screen-reading game bots** (emulator + OpenCV), and **(3) physical robots playing board games**.
- Almost nobody combines a physical robot with a vision agent on a phone. That's our niche ([[Prior Art — Touchscreen Robots and Software Agents]]).
- Real-money online poker is the one area to avoid: operators ban real-time assistance and bots outright, confiscate funds, and run dedicated detection teams.

## 1. Physical device-testing robots

- **TapsterBot** (Jason Huggins, creator of Selenium): open-source BSD delta robot for mobile testing; Arduino + 3 servos + printed parts, ~€250; driven by a Node.js server, with Appium integration and Robot Framework keywords (taps, swipes, stress gestures) [1][2][3]. It grew out of an earlier **belt-driven Cartesian** design (BitBeam Bot); the delta was chosen for speed and simplicity, but deltas are harder to make precise [1][3]. Tapster 2 is retired from sale; the designs stay open [3].
- **TestDevLab** built its own robot for automated "manual" mobile testing [4].
- **Lesson:** the testing world solved tap and swipe actuation a decade ago. What's new for us is the **vision agent and game brain** on top.

## 2. Software game bots (no robot)

- Commercial bot services run games in **Android emulators** with **OpenCV image recognition + scripted decisions** [5]. That's the same perception → decision loop, minus the physical layer.
- A pending patent, CA3167360A1 "Mobile gaming bot and system", mentions a robot, user actions and optical sensors (only metadata seen) [6].
- **Our previously cited "BrainyBot/TappingBot"** (CV robot tapping phone games, in [[Agents — VLM GUI Agents and Vision Grounding Survey]]) **could not be re-verified** in this search. Treat it as unconfirmed until someone checks the repo.

## 3. Physical robots playing board games

- Student and academic projects combine CV + AI + a robot arm for board games (e.g. an HKU Chinese Checkers robot arm) [7]. The same architecture applies, but they manipulate physical pieces rather than a screen.

## 4. Where not to go: real-money online card rooms

- **PokerStars:** zero tolerance for real-time assistance (RTA), permanent bans; detection uses behavioural indicators, including "perfect GTO" play or solver use only at critical moments, across billions of hands [8][9].
- **GGPoker:** bans any external tool that gives an edge or influences decisions in real time, *including charts*; penalties include permanent bans and **confiscation of funds**. 31 accounts were blocked in Feb 2025 with GTO Wizard's Fair Play Check, and 40+ high-stakes accounts banned with $1.2M+ confiscated in 2020 [10][11][12].
- **Why it's out of scope:** in multiplayer real-money games a bot takes money from other people. It's cheating, not research. Our card work targets single-player, offline and play-money games, plus our own apps.

## Pitch in

- [ ] Anyone: check the DeMaCS-UNICAL/TappingBot repo; update the VLM survey note if it's real, or remove the claim.
- [ ] Robotics: read the TapsterBot calibration code; borrow anything useful for our calibration.

## Sources

1. [QCon NY 2013 — Tapster talk](https://qconnewyork.com/ny2013/node/333.html) `[Documented]`
2. [TapsterBot wiki — Robot Framework keywords](https://github.com/pylapp/tapsterbot/wiki/07-%5C--Drive-the-robot:-Robot-Framework-keywords) `[Documented]`
3. [Tapster — Robot as a Service](https://write.as/pylapp/tag:tests) · [Tindie — Tapster](https://blog.tindie.com/2016/09/tapster-manipulates-phone-automatically) · [SlideShare deck](https://www.slideshare.net/slideshow/dont-fear-our-new-robot-overlords-a-new-way-to-test-on-mobile/37275458) `[Community]`
4. [TestDevLab — testing robot](https://www.testdevlab.com/blog/how-we-built-a-robot-for-automated-manual-mobile-testing) `[Community]`
5. [AI-powered bots in casual mobile gaming (press release)](https://business.minstercommunitypost.com/minstercommunitypost/article/abnewswire-2025-12-1-how-ai-powered-bots-are-quietly-reshaping-even-casual-mobile-gaming) `[Community]`
6. [CA3167360A1 — Mobile gaming bot (Google Patents)](https://patents.google.com/patent/CA3167360A1/en) `[Documented]`
7. [HKU FYP — Chinese Checkers robot](https://wp2024.cs.hku.hk/fyp24057/wp-content/uploads/sites/58/2025/05/Fyp_Final_Report_2.pdf) `[Community]`
8. [PokerNews — PokerStars vs RTA](https://www.pokernews.com/news/2023/10/pokerstars-battle-against-real-time-assistance-44628.htm) `[Documented]`
9. [Pokerfuse — inside PokerStars' RTA arsenal](https://pokerfuse.com/news/poker-room-news/219952-inside-pokerstars-arsenal-how-it-combats-rta/) · [PokerNews — how PokerStars deals with bots](https://www.pokernews.com/news/2020/04/how-does-pokerstars-deal-with-bots-37068.htm) `[Documented]`
10. [PokerNews — GGPoker × GTO Wizard](https://www.pokernews.com/news/2025/03/ggpoker-and-gto-wizard-team-up-to-keep-poker-fair-48110.htm) `[Documented]`
11. [Pokerfuse — GGPoker reimburses 4,000+ players](https://pokerfuse.com/news/poker-room-news/211765-ggpoker-reimburses-over-4000-players-following-recent-rta/) `[Documented]`
12. [PokerNews — Fedor Holz on WSOP bans](https://www.pokernews.com/news/2025/03/fedor-holz-hints-at-wsop-bans-for-ggpoker-rule-breakers-48061.htm) `[Documented]`

## Related

- **Summary:** [[State of — System Design]] · [[State of — Robotics]] · [[State of — Cybersecurity]]
- **See also:** [[Betting Apps — Behavioral and Automation Detection]] · [[Game Theory — Poker AI Milestones (Cepheus to Pluribus)]] · [[Game Theory — Real-Time Poker Under Personal Compute and Time Banks]] · [[Poker Platforms — RTA Bot and Solver Detection]]

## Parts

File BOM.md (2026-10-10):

# Bill of Materials — iPhone-Ian v2

**Design:** CoreXY gantry, 2 phones, MKS DLC32 + FluidNC, spring-loaded grounded stylus. Full design: `aria/hardware-concept-v2.md`.

**Ordered 2026-10-08.** What was actually bought differs from this list in places (belt → PU steel-core, idlers → Mellow bearing type, heat-set inserts + screws reused from Olyntia). See `aria/LOG.md` for the as-ordered list. Still open: #23–24 (Amazon) and #25 (plate).

**Status:** prices verified 2026-10-01 (C$, before tax). **Recheck at order time** — AliExpress prices drift. Order target: weekend of 2026-10-10/11, so shipping (~2–3 weeks) overlaps printing and the plate quote.

**Split:** total ~C$325 + tax, 50/50 between Aria and Marc (≈ C$163 each before work-sourcing). Tick the **Aria (work)** / **Marc (work)** column for anything you can get free through work — it comes off the order.

---

## 1. AliExpress — electronics, motion, hardware (one order)

| # | Part | Pick | Qty | C$ | Aria (work) | Marc (work) |
|---|---|---|---|---|---|---|
| 1 | MKS DLC32 V2.1 controller | board only | 1 | 26.85 | ☐ | ☐ |
| 2 | BIGTREETECH TMC2209 drivers | 4-pack | 1 | 23.21 | ☐ | ☐ |
| 3 | STEPPERONLINE 17HE08-1004S motor | 23 mm, 1 A, 20 mm shaft | 2 | 24.16 | ☐ | ☐ |
| 4 | MG90S servo | 180° (not 360°/continuous) | 2 | 5.89 | ☐ | ☐ |
| 5 | 24 V PSU | 3 A, barrel | 1 | 10.93 | ☐ | ☐ |
| 6 | Mini560 **PRO** buck → 5 V | PRO only (6–30 V in) | 1 | 5.07 | ☐ | ☐ |
| 7 | Mechanical endstops w/ cable | 3-pack | 1 | 3.97 | ☐ | ☐ |
| 8 | MGN9H linear rail + block | 230 mm | 3 | 39.15 | ☐ | ☐ |
| 9 | 2020 V-slot extrusion (bridge) | 240 mm | 1 | 6.39 | ☐ | ☐ |
| 10 | GT2 belt, 6 mm rubber/aramid | 5 m | 1 | 6.16 | ☐ | ☐ |
| 11 | 20T motor pulley, 5 mm bore | for 6 mm belt | 2 | 6.86 | ☐ | ☐ |
| 12 | 20T idler, 3 mm bore | 6 toothed + 4 smooth | 10 | 25.62 | ☐ | ☐ |
| 13 | M3 brass heat-set inserts | — | 1 lot | 7.54 | ☐ | ☐ |
| 14 | M3 DIN912 cap screws | 8/12/16/20/25/50 mm | 1 lot | ~14 | ☐ | ☐ |
| 15 | M3 nyloc nuts | — | 1 lot | 2.83 | ☐ | ☐ |
| 16 | M3 shim washers, 0.5 mm | — | 1 lot | 2.38 | ☐ | ☐ |
| 17 | M3 T-nuts for 2020 | — | 1 lot | 2.94 | ☐ | ☐ |
| 18 | Brass tube, 5 mm OD, 0.25 wall | 4.5 ID fits stylus stem | 1 | ~7.41 | ☐ | ☐ |
| 19 | Compression springs, 0.5 mm wire | ~7 mm OD × 20 mm | 1 lot | ~5.28 | ☐ | ☐ |
| 20 | Silicone hookup wire, 26 AWG | 5 m | 1 | 3.78 | ☐ | ☐ |
| 21 | Servo extension, 1-to-1 | 50 cm | 1 | 2.29 | ☐ | ☐ |
| 22 | DC jack adapter, female 5.5×2.5 | — | 1 | 2.04 | ☐ | ☐ |
| | **AliExpress subtotal** | | | **~235** (~266 w/ HST) | | |

## 2. Amazon.ca — prices confirmed 2026-10-08, shipping to Waterloo N2J

| # | Part | Pick | Qty | C$ | Ship | Aria (work) | Marc (work) |
|---|---|---|---|---|---|---|---|
| 23 | PATIKIL stylus tips, 6 mm mesh, threaded metal stem | 5-pack, 6 mm variant (AliExpress only sells active Apple Pencil nibs — won't work). **Only ~6 in stock — buy now.** | 1 | 8.49 | free if in a $35+ Amazon order, else ~6 | ☐ | ☐ |
| 24 | 6061 rail risers, 10×20 mm | COYOUCO 10×20×500 (cut in half → 2 × ~240 mm). Separate seller (COYOUCO-CA), **slow: delivers ~Oct 30–Nov 20.** Or Metal Supermarkets Kitchener for pickup. | 1 | 26.64 | 5.54 | ☐ | ☐ |

## 3. JLCCNC — order AFTER the plate CAD exists

| # | Part | Pick | Qty | C$ | Aria (work) | Marc (work) |
|---|---|---|---|---|---|---|
| 25 | Base plate, 3 mm aluminium, 340.6×320 mm, 40 M3 holes (mostly **slotted**) | drafted 2026-10-10: `aria/cad/base_plate.dxf` (laser profile), `base_plate.py` (source). Check in Onshape, then quote | 1 | ~50 incl. ship | ☐ | ☐ |

## 4. Already owned — C$0

| Item | What | Role |
|---|---|---|
| Compute / host | Marc's PC: multi-year gaming CPU, 32 GB DDR4, **GTX 1080 (8 GB VRAM)**, M.2 SSD | Runs FluidNC's host driver **and** the local model (training + inference). The 8 GB VRAM is the binding constraint on model size — see `PIPELINE.md`. |
| 3D printers | Aria (Elegoo Centauri, CF filaments) + Marc's | All printed parts, free filament |
| Test phone(s) | Spare iPhone(s), test Apple ID, no personal accounts | Target device |

**Printed (CF-PETG / TPU):** corner idler posts + plates, side walls, motor clamps + legs, bridge end blocks + plates, toolhead plate + lever + stylus sleeve, belt clamp, endstop mounts, 2 phone slots, cable guides, feet, controller box.

---

## Final estimate — tax in, shipped to Waterloo, ON (HST 13%)

Checked 2026-10-08. Amazon prices are confirmed live; AliExpress prices use the 2026-10-01 browser-selected baseline (see note below).

| Order | Goods (C$) | Shipping | HST 13% | All-in (C$) |
|---|---|---|---|---|
| AliExpress (#1–22) | ~235 | free | ~30.6 | **~266** |
| Amazon.ca (#23–24) | 35.13 | 5.54 (+~6 if stylus unbundled) | ~5.3–6.1 | **~46–53** |
| JLCCNC plate (#25) | ~50 incl. ship | — | ~0–6.5 at import | **~50–57** |
| **Total** | | | | **≈ C$360–375** |

**≈ C$370 all-in. Split 50/50 ≈ C$185 each**, before anyone's work-sourcing ticks (each tick drops both shares).

**Why not cent-exact on AliExpress:** the listings render in CAD and ship free to Canada (HST added at checkout), but each item's displayed price depends on the variant selected and on account-specific coupons / new-shopper promos — e.g. the controller listing currently flashes a C$1.74 "new shopper" price on a *shell* variant, not the C$26.85 board. Your real cart total is whatever your own account shows at checkout, and it will likely be **lower** than this baseline once coupons apply, not higher. Recheck in your cart before paying.

## Before you place the order
- [ ] Recheck every AliExpress price and that each listing is still live.
- [ ] Marc ticks his work-sourcing column; Aria ticks his. Remove what's covered.
- [ ] Decide who places each order and the ship-to address.
- [ ] Order #23 (stylus tips) regardless — cheap and on the critical path.
- [ ] Hold #25 (plate) until its drawing is done.

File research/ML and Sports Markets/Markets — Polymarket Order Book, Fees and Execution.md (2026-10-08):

---
type: research
status: answered
author: marc
date: 2026-10-07
tags: [sports-analytics, machine-learning, cybersecurity, ml-and-sports-markets, polymarket, clob, market-microstructure, fees, execution, maker-taker]
---

# Markets — Polymarket Order Book, Fees and Execution

**TL;DR**
- Since 2026 Polymarket sports markets charge **taker fees that peak at a 50¢ price**. Makers pay nothing and get rebates.
- The tennis fade trades around mid-prices right after a break, which is exactly where taker fees are highest. So **post limit orders (maker) at fair value** rather than hitting the book.
- The catch is **adverse selection**: in-play, faster traders (courtsiders, faster feeds) pick off stale quotes.

**Builds on:** [[Betting Apps — Behavioral and Automation Detection]] §6 (the API is the sanctioned route) and [[Tennis — In-Play Market Research]] (the strategy).

## Mechanics

- Each outcome is a token on a **central limit order book**. The book is public with no auth. It returns `tick_size` (0.1 / 0.01 / 0.001 / 0.0001 per market), `min_order_size` (often 5) and `neg_risk`. `[Documented]`
- **Order types:** GTC and GTD (resting limit orders), FOK and FAK (immediate). Prices must be multiples of the tick. `[Documented]`
- Orders are signed with EIP-712. The API is the documented bot and market-maker path. Polymarket geo-blocks by jurisdiction, so check eligibility for each member's location before anyone trades. `[Documented]`

## Fees (2026, and they change, so read them live)

- Sports fees began on **18 Feb 2026** (NCAAB and Serie A first) and **Fee Structure V2** took effect on **30 Mar 2026**. Fees are **taker-only**, follow a **price curve** (highest at 0.50, near zero at the extremes), and are taken in shares on buys and USDC on sells. `[Documented]`
- **Maker rebates** for sports are listed at 25% of taker fees in the docs; another summary says 20%. A **taker rebate tier** program started 28 May 2026. `[Documented]` (conflicting figures)
- **Polymarket US** (the separate CFTC-regulated exchange) has its own schedule: sports takers ~5% at peak under the 1 Jul 2026 schedule, makers free. `[Community]`
- **Action:** read `feesEnabled` and the fee parameters from each market object at runtime. Never hard-code them.

## What this means for the tennis fade

| Choice | Pros | Cons |
|---|---|---|
| **Take** (FOK/FAK) right after a break | Guaranteed fill while the overreaction is live | Peak taker fee at mid-prices; crossing the spread |
| **Make** (GTC at model fair value ± margin) | No fee, plus rebate; earn the spread | May not fill; **adverse selection**: you get filled exactly when someone knows more (a point already played) |

- Feed latency: official in-play feeds run ~5–30 s behind live, and broadcast another 20–45 s ([[Betting Apps — Behavioral and Automation Detection]] §5). Quotes must be pulled **instantly** on any point event, and a resting maker needs a feed at least as fast as the takers'.
- Hybrid: rest maker orders when the market is calm, and only take when edge − fee − spread > threshold.

## Liquidity reality check

- Depth limits stake size. Before modelling ROI, pull the book for 20+ live tennis matches and log spread and depth at the top 3 levels over the match. That decides whether the strategy is worth more than pocket money.

## Pitch in

- [ ] ML: write a book recorder (websocket or polling) for live tennis markets to parquet; post spread and depth statistics here.
- [ ] Security: review key management for the signing wallet (hardware wallet or vault; never in the repo or vault).

## Sources

- [Polymarket — fees](https://docs.polymarket.com/trading/fees) · [maker rebates](https://docs.polymarket.com/polymarket-learn/trading/maker-rebates-program) · [taker rebates](https://docs.polymarket.com/trading/taker-rebates.md) · [order book](https://docs.polymarket.com/trading/orderbook) · [create orders](https://docs.polymarket.com/trading/orders/create) `[Documented]`
- [Pine Analytics — fee rollout](https://pineanalytics.substack.com/p/polymarket-fee-rollout) · [River Markets — Polymarket US fees](https://www.rivermarkets.com/insights/polymarket-us-fees.html) `[Community]`

## Related

- **Summary:** [[State of — Sports Analytics]] · [[State of — Machine Learning]] · [[State of — Cybersecurity]] · [[State of — ML and Sports Markets]]

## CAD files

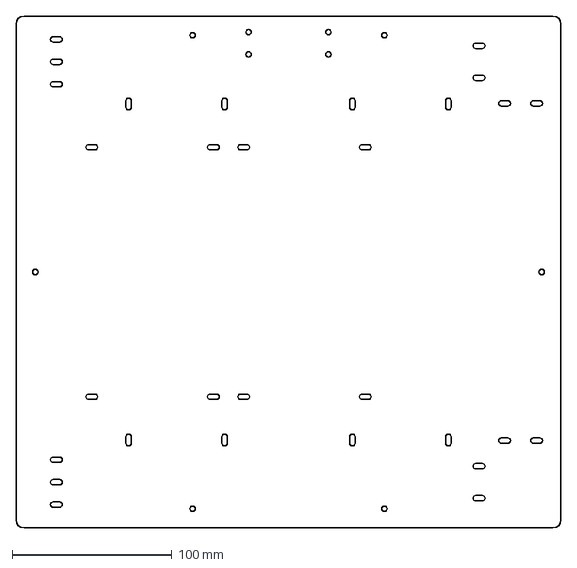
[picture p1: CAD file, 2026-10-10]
aria/cad/base_plate.dxf
340.6 x 320.0 mm

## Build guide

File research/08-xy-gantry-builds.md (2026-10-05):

---
tags: [gantry, corexy, grbl, arduino, microcontroller, stepper, pen-plotter, mechanical]
status: answered
date: 2026-10-05
related:
  - "[[01-prior-art-notes]]"
  - "[[02-mechanical-architecture-notes]]"
  - "[[../specs/01-hardware]]"
---

# XY gantry, CoreXY & microcontroller — phone-tapping builds

## Question

What XY/CoreXY gantry builds exist for touchscreen automation? What microcontroller + firmware setup is simplest for a 2-axis Cartesian gantry with a servo Z-axis?

## Key findings

### XY gantry / CoreXY for touchscreen automation

- **No documented CoreXY phone-testing builds found.** CoreXY is popular for 3D printers and pen plotters, but nobody publicly documents using it to tap phone screens.
- **Delta robots dominate** touchscreen testing: Tapster, Tappy, ABB FlexPicker, igus delta.
- **Simple belt-driven Cartesian XY exists** in the pen plotter world — easily adapted. The 1c3d pen plotter: "not CoreXY — for a plotter's light loads, independent X and Y belts driven by their own steppers are simpler to build and tune." `[Community]` https://1c3d.com/projects/build-belt-driven-xy-pen-plotter-grbl-servo
- **TestDevLab explicitly considered and abandoned CNC gantry** for Tappy: "It was difficult to adapt CNC's configuration and software for touchscreen testing." They went delta, but for general phone testing (not our fixed-mount use case).
- **Echo Robot Pen Plotter** uses a spring-loaded pen holder — directly applicable to our Z-axis compliance. `[Community]`
- **Phone-Swiper** (UMN capstone): 2 LIDAR + 2 servo arms, Arduino Nano. Not gantry but adjacent. `[Academic]` https://github.com/bkringlie/Phone-Swiper
- **Touchscreen Testing Robot** (ofer9430): lead screw + A4988 + drawer slide for one axis, SG90 servo for Z. Uses battery negative pole as capacitive tip. `[Community]` https://www.instructables.com/Robot-De-Testeo-Para-Pantalla-Touchscreen/

### Instructables "Screen Tapping Robot" deep dive

Source of truth for our build. By MasterGinger, July 2017. https://www.instructables.com/Screen-Tapping-Robot/

- **Platform:** 9"×12" pattern plate with grommets + standoffs to lock phone
- **X-axis:** Lead screw + NEMA 17 stepper + 2× 8mm×300mm stainless precision shafts with linear ball bearings
- **Y-axis:** Aluminum pulleys + timing belt (explicitly lighter than lead screw — second lead screw "too heavy"). Two channel sliders for stylus mount.
- **Z-axis:** Custom pulley system, standard servo (not stepper). Author initially wanted linear actuator but found it too big/expensive.
- **Electronics:** Raspberry Pi 3 + 2× A4988 stepper drivers. Servo on Pi PWM.
- **Known problems:**
  - Stylus grounding is the #1 problem. Commenter confirms: screen doesn't feel pen when attached to robot, feels it when human holds it. Fix: wire from pen to common 0V.
  - No published code or wiring diagram — reverse-engineering from photos.
  - Polar coordinate system was tried and abandoned ("much less stable").

**What's different from Tappy delta:** 2-motor Cartesian vs 3-motor delta. No kinematics math. Heavier gantry (X carries Y carries Z). Simpler calibration. Slower movement.

### Microcontroller: Arduino Uno + CNC Shield V3 is the answer

**Recommendation:** Arduino Uno clone (~$3) + CNC Shield V3 (~$5) + 2× A4988 (~$3) + MG90S servo (~$3). Total: **~$14.** Flash GRBL 1.1h, set laser mode, wire servo to spindle pin. Done.

| Option | Cost | Complexity | 2-Axis + Servo | Verdict |
|---|---|---|---|---|
| **Arduino Uno + CNC Shield V3 + A4988** | ~$15 | Lowest | Yes (servo on spindle pin via laser mode) | **Simplest. Cheapest.** |
| Arduino Nano + CNC Shield V3 | ~$12 | Low | Same as Uno | Smaller, same limits |
| Arduino Mega + RAMPS 1.4 | ~$30 | Medium | Overkill for 2-axis | Only if more I/O needed later |
| ESP32 + grblHAL / FluidNC | ~$8-15 | Medium-high | Yes + WiFi | Only if WiFi G-code streaming needed |
| Dedicated GRBL board (Protoneer) | ~$25-50 | Medium | All-in-one | Cleaner wiring, more $ |

Key details from ElectricalFlux GRBL guide (Jul 2026): Mainline GRBL 1.1h uses ~28.5KB of ATmega328P's 32KB flash — tight but functional. "For simple 2-axis, Uno is still the correct choice." `[Documented]`

- **Clone shield warning:** Cheap CNC Shield V3 clones often have Z+ limit switch pin incorrectly routed (tied to Spindle Enable). Fix by cutting trace or buying genuine Protoneer.
- **Vref for A4988:** Vref = Imax × 0.8. For NEMA 17 @ 1.5A, set to 1.2V.
- **Servo control:** `$32=1` (laser mode) — GRBL treats spindle PWM pin as dynamic output. Servo needs intermediate driver (GRBL spindle output is 0-5V PWM, not servo signal). 1c3d build confirms this works.

### GRBL approach benefits

Standard G-code interface: `G0 X50 Y80` to move, `M3`/`M5` to tap. Industry standard tooling (UGS, bCNC, Python serial) works out of the box. No inverse kinematics — X/Y map directly to screen coordinates after simple affine calibration.

### Instructables robot used Raspberry Pi — why we shouldn't

Raspberry Pi 3 is heavier, more expensive, requires A4988 drivers wired manually. Uno + CNC shield is cheaper, simpler, all-in-one. The Pi approach also means custom GPIO code instead of battle-tested GRBL. Use the Pi (or Mac) as the host that sends G-code over USB serial; keep the microcontroller simple.

## Sources

- https://www.instructables.com/Screen-Tapping-Robot/
- https://1c3d.com/projects/build-belt-driven-xy-pen-plotter-grbl-servo
- https://electricalflux.com/mcu-general/grbl-on-arduino-compatibility-shield-pinout-guide
- https://github.com/bdring/Grbl_Esp32
- https://www.reddit.com/r/hobbycnc/comments/nhbwz8/gbrlhal_vs_grbl_esp32_pros_and_cons
- https://www.instructables.com/Robot-De-Testeo-Para-Pantalla-Touchscreen/
- https://github.com/bkringlie/Phone-Swiper

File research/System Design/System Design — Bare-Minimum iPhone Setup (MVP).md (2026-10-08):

---
type: research
status: in-progress
author: marc
date: 2026-10-07
tags: [system-design, robotics, cybersecurity, mvp, iphone, bill-of-materials]
---

# System Design — Bare-Minimum iPhone Setup (MVP)

**TL;DR**
- The smallest setup that plays a card game on a real iPhone: **a spare iPhone, a clamp, a grounded stylus on any XY motion platform, a USB cable to a Mac for screen capture, and ~300 lines of Python.**
- We both have 3D printers, so the **printer itself can be the interim gantry** (it already speaks G-code) while hardware v2 gets built.
- First milestone: tap "New Game", then complete one Solitaire move with verification.

**Builds on:** [[System Design — Card-Playing Gantry Rig Architecture]], Aria's hardware v2 (`aria/hardware-concept-v2.md` in the repo), [[Rig — iPhone Screen Capture Paths (USB, AirPlay, Multi-Phone)]].

## Bill of materials, two tiers

| Item | Tier 0: this week, ~$0–30 | Tier 1: hardware v2 |
|---|---|---|
| Phone | Spare or old iPhone, test Apple ID, no personal accounts | Same, ×2 slots |
| Motion | **Existing 3D printer** (Marlin/Klipper) with a stylus where the nozzle would be | CoreXY on MGN9, MKS DLC32 + FluidNC |
| Z / tap | Printer Z axis (slow but fine for turn-based) | MG90S servo, spring-loaded |
| Stylus | Capacitive stylus tip + **wire to machine ground** (mandatory for PCAP) | Same, conductive silicone tip |
| Fixture | Printed phone cradle bolted to the bed | Phone slots in the base plate |
| Screen in | **USB → Mac**, AVFoundation capture | Same, or UxPlay per phone |
| Host | Mac/PC with Python: `opencv-python`, `pyserial`, `numpy` | + GPU box for models |

Capacitive physics and grounding: [[Gantry — Capacitive Touch Physics and Architecture]]. A Tapster-class delta was ~€250 with an Arduino, 3 servos and printed parts [1]. The printer route is cheaper still, because we own the printers.

## Phone prep checklist

- [ ] Auto-Lock **Never**, brightness fixed, True Tone and Night Shift off (stable colours for perception)
- [ ] Notifications off / Focus on (they cover cards, and they're a prompt-injection channel: [[Security — Prompt Injection and Pop-up Attacks on GUI Agents]])
- [ ] An offline card game installed; ads off if possible
- [ ] Triple-click Accessibility Shortcut disabled ([[iOS — Face ID, Autofill and 2FA Constraints]])
- [ ] Orientation lock on, so the layout doesn't rotate mid-game

## Software, minimum viable (in this order)

1. **`capture.py`:** grab frames from the USB-attached iPhone (AVFoundation) and save PNGs.
2. **`calib.py`:** tap 4 known screen points by jogging, then fit a screen px → machine mm homography ([[Rig — Camera-to-Screen Calibration with ChArUco]]; with screen capture, px are exact).
3. **`robot.py`:** `tap(x, y)`, `drag(path)`; G-code over serial (`G0` for moves, Z down/dwell/up); soft limits = screen rectangle.
4. **`see.py`:** template-match card corners, or a pretrained playing-card YOLO ([[System Design — Reading Cards from the Screen]]).
5. **`play.py`:** state machine + a greedy move picker → plan → act → verify.

## Day-by-day

| Day | Done when |
|---|---|
| 1 | Phone clamped; stylus grounded; one manual G-code tap registers |
| 2 | Frames captured on the Mac at ≥10 fps |
| 3 | Calibration error ≤1 mm across the screen |
| 4 | `tap()` hits "New Game" 20/20 times |
| 5 | `drag()` moves a card between piles 18/20 |
| 6 | Card recognition ≥99% on 200 captured frames |
| 7 | Plays a full Solitaire game with verification, logging each step |

## Pitch in

- [ ] Robotics: printed stylus mount + ground wire for one of our printers; post the Day 1 video.
- [ ] Anyone: test whether USB capture works while the printer runs (cable routing, EMI).

## Sources

1. [TapsterBot overview — cost, design (SlideShare)](https://www.slideshare.net/slideshow/dont-fear-our-new-robot-overlords-a-new-way-to-test-on-mobile/37275458) `[Community]`
2. [TapsterBot GitHub wiki — Robot Framework keywords](https://github.com/pylapp/tapsterbot/wiki/07-%5C--Drive-the-robot:-Robot-Framework-keywords) `[Documented]`
3. [TestDevLab — building a robot for manual mobile testing](https://www.testdevlab.com/blog/how-we-built-a-robot-for-automated-manual-mobile-testing) `[Community]`

## Related

- **Summary:** [[State of — System Design]] · [[State of — Robotics]] · [[State of — Cybersecurity]]
- **See also:** [[Gantry — FluidNC Control Interface (Jogging, Soft Limits, Realtime)]] · [[System Design — Drag, Tap and Verify Primitives for Card Moves]]

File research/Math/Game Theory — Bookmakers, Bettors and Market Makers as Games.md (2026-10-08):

---
type: research
status: answered
author: marc
date: 2026-10-07
tags: [sports-analytics, cybersecurity, ml-and-sports-markets, math, game-theory, adverse-selection, bookmaking, market-microstructure]
---

# Game Theory — Bookmakers, Bettors and Market Makers as Games

**TL;DR**
- **Levitt (Economic Journal 2004):** bookmakers *don't* balance their books like financial market makers. They **set prices away from market-clearing to exploit bettor biases** and take the risk, because they forecast better than most bettors.
- Financial market makers instead widen spreads to cover **adverse selection** from informed traders (the Glosten–Milgrom logic).
- Account limiting ([[Betting — Account-Level Behavior Models]]) is the bookmaker's move in a **screening game**: find and remove informed players.
- Prediction-market CLOBs bring back the financial structure, which is why bots are welcome there.

**Builds on:** [[Game Theory — GTO vs Exploitative Play (Poker and Markets)]] and [[Markets — Market Making in Binary Contracts (Avellaneda-Stoikov)]].

## Levitt's puzzle and answer

- **Puzzle:** gambling and financial markets are both zero-sum with heterogeneous beliefs and big money, yet they're organised completely differently [1].
- **Answer:** the bookmaker "does not play the traditional role of market makers matching buyers and sellers but, rather, takes large positions" [1][2]. It can out-forecast bettors **and** shade prices toward bettor biases; rational bettors limit how far it can shade [1].
- **Evidence:** an online bookmaker's NFL contest, 2001–02: 285 entrants, 19,770 bets, 242 games. Aggregate risk to the book was minimal, and there was little evidence of bettors who could systematically beat it [2][3].

## Adverse selection (Glosten–Milgrom, background)

A market maker trading against a mix of informed and uninformed traders loses to the informed and recovers from the uninformed via the **spread**. More informed flow → wider spread → prices update after each trade (each trade carries information). This is standard theory, not from our search results; Levitt's paper discusses the contrast [1].

## Three games in the betting ecosystem

| Game | Players | Equilibrium logic | Our relevance |
|---|---|---|---|
| **Pricing** | Book vs bettors | Book shades lines toward biases; informed bettors cap the shading | Biases persist where informed money is limited, i.e. retail in-play |
| **Screening** | Book vs sharps | Profile behaviour → limit or ban winners (a separating equilibrium) | [[Betting — Account-Level Behavior Models]]; why the sanctioned API venue matters |
| **Market making** | Maker vs informed takers | Spread ≥ expected loss to informed flow; requote on news | Our maker quotes in-play: pull quotes at point end ([[Markets — Polymarket Order Book, Fees and Execution]]) |
| **Detection** | Platform vs automation | Attacker–defender arms race | [[Betting Apps — Behavioral and Automation Detection]] (security view) |

## Research directions

- **Measure adverse selection on Polymarket tennis:** after our simulated maker fills, does the price move against us within 10 s? The answer sets the minimum spread.
- **Levitt-style bias test:** do Polymarket tennis prices shade toward popular players (name recognition) beyond what the model says?

## Sources

1. [Levitt — Why are Gambling Markets Organised So Differently from Financial Markets? (EJ 2004, PDF)](https://www.stat.berkeley.edu/%7Ealdous/157/Papers/Levitt_Gambling_2004.pdf) · [IDEAS](https://ideas.repec.org/a/ecj/econjl/v114y2004i495p223-246.html) `[Benchmark]`
2. [Levitt — How Do Markets Function? (NBER w9422)](https://www.nber.org/papers/w9422) `[Benchmark]`
3. [AcaWiki summary](https://acawiki.org/Why_are_Gambling_Markets_Organised_So_Differently_from_Financial_Markets%3F) `[Community]`

## Related

- **Summary:** [[State of — Sports Analytics]] · [[State of — Cybersecurity]] · [[State of — ML and Sports Markets]] · [[State of — Math]]

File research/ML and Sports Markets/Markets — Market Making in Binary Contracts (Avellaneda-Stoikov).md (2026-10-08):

---
type: research
status: answered
author: marc
date: 2026-10-07
tags: [machine-learning, ml-and-sports-markets, market-making, avellaneda-stoikov, inventory-risk, polymarket]
---

# Markets — Market Making in Binary Contracts (Avellaneda-Stoikov)

**TL;DR**
- Being the maker avoids fees and earns rebates ([[Markets — Polymarket Order Book, Fees and Execution]]). It also needs an inventory model, or "market making" quietly becomes a directional bet.
- **Avellaneda–Stoikov (AS)** gives a reservation price and spread that skew quotes against your inventory.
- For binary contracts it needs changes: prices bounded in [0, 1], **Bernoulli variance** instead of volatility, and a **terminal penalty** because inventory settles at exactly 0 or 1. A Polymarket thesis that did this reported ~155 USDC per market on its test set.

## Classical AS in one paragraph

A market maker quotes around a **reservation price** r = mid − q·γ·σ²·(T − t), where q is inventory, γ risk aversion, σ volatility and T − t time left. It quotes a spread that widens with γ, σ and order-arrival intensity. Long inventory → lower quotes to sell it off [1][2].

## Why binary contracts break it

- Prices live in [0, 1] and **snap to 0 or 1 at settlement**. As resolution nears, the market goes one-sided, so inventory has to be managed more aggressively than in classical markets [3].
- Feil & Nendel model the price as a conditional probability driven by a latent belief diffusion. The maker maximises terminal wealth while controlling **both mark-to-market and settlement risk**: "fundamentally different" from classical settings [4].

## The Polymarket adaptation (Comillas thesis)

- Prices bounded to [0, 1]; **Bernoulli variance p(1 − p)** replaces historical volatility; **normalised inventory**; **terminal risk penalty** for settlement [5].
- Goal: earn the spread "without becoming a hidden directional bet", not forecast outcomes [5].
- Result: ~**155 USDC per market** on the test set; CVaR showed sensitivity to tail events and the small sample [5].

## For in-play tennis

- **Variance isn't smooth.** p jumps on every point, and jumps are largest on high-importance points ([[Markets — Point Importance and Leverage in Tennis]]). Scale the spread with **point importance**, not a constant σ.
- **Adverse selection:** pull or widen quotes the instant a point ends, until the feed confirms the new score. Faster participants pick off stale quotes.
- **Combine with the fade:** skew the reservation price toward the *model's* fair value instead of the mid. That's market making with a view, which is the natural form for an edge-holder.
- **RL extension:** a 2026 paper keeps AS's HJB structure but lets the market state pick the AS parameters [6]. That's a sensible small RL problem for a simulator ([[Markets — In-Play Entry, Exit and Sequential Decisions]]).

## Pitch in

- [ ] ML: implement binary-AS on recorded tennis books (paper trading); measure spread capture vs adverse selection by point type.

## Sources

1. [Hummingbot — AS strategy deep dive](https://hummingbot.org/blog/technical-deep-dive-into-the-avellaneda--stoikov-strategy/) `[Community]`
2. [RL to improve AS market making (PMC9767337)](https://www.ncbi.nlm.nih.gov/pmc/articles/PMC9767337/) · [Guéant et al. — inventory risk (arXiv 1105.3115)](https://arxiv.org/pdf/1105.3115) `[Benchmark]`
3. [Prediction market making guide](https://newyorkcityservers.com/blog/prediction-market-making-guide) `[Community]`
4. [Feil & Nendel — Optimal market making in prediction markets (arXiv 2607.17991)](https://arxiv.org/pdf/2607.17991) `[Benchmark]`
5. [Comillas thesis — AS on Polymarket](https://repositorio.comillas.edu/jspui/handle/11531/109133) `[Benchmark]`
6. [Zero-shot adaptation to order book dynamics (arXiv 2605.21707)](https://arxiv.org/pdf/2605.21707) `[Benchmark]`

## Related

- **Summary:** [[State of — Machine Learning]] · [[State of — ML and Sports Markets]]

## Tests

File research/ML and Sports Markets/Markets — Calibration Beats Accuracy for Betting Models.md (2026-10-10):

---
type: research
status: answered
author: marc
date: 2026-10-07
tags: [sports-analytics, machine-learning, ml-and-sports-markets, calibration, brier, log-loss, model-selection, betting]
---

# Markets — Calibration Beats Accuracy for Betting Models

**TL;DR**
- For betting, choose models by **calibration** (are the 60% calls right 60% of the time?), not accuracy.
- Walsh & Joshi (2024, NBA): calibration-selected models averaged **+34.7% ROI** vs **−35.2%** for accuracy-selected.
- Calibration also needs measuring **where you actually bet**: on games where your model disagrees with the market. That's exactly where models are worst calibrated.

**Builds on:** [[Tennis — In-Play Market Research]] (the Markov/Elo fair-value model). This note says how to *grade* it.

## Why accuracy misleads

- Accuracy only asks whether the favourite won. Betting pays on **price vs probability**: a 55% call against a 50% price is a bet; a 90% call against a 92% price isn't.
- **Walsh & Joshi (Machine Learning with Applications 16, 2024):** trained on several NBA seasons, bet one season at published odds. Calibration-based selection averaged +34.69% ROI vs −35.17% for accuracy-based selection (best case +36.93% vs +5.56%). One season of one sport, and bet sizing wasn't checked, so treat this as directional. `[Benchmark]`

## What to measure

| Metric | What it tells you |
|---|---|
| **Log loss** | Strictly proper; punishes confident misses hard. The primary metric. |
| **Brier score** (+ its reliability/resolution split) | Proper and intuitive. The reliability term *is* calibration error. |
| **Reliability diagram / ECE** | Visual check by probability bin. Use ≥10 bins with enough samples each. |
| **Calibration vs market** | Same diagram, but bin by *model − market* edge. This is the new piece below. |

## Calibration where it matters

- You only bet when model ≠ market. That subset is biased toward the model's **errors**: a winner's-curse selection effect.
- Plot outcome frequency against model probability **only for bets placed**, and bin by edge size. If big-edge bets win less often than the model claims, the "edge" is mostly model error. **Shrink toward the market** ([[Markets — Model plus Market - Blending and the Benter Test]]).
- For in-play tennis, also bin by **score state** (e.g. right after a break). The fade lives in exactly that state, and the i.i.d.-points assumption is weakest there.

## Recalibration toolbox

- **Platt / logistic** on logit(p). **Isotonic** when you have lots of data. **Temperature scaling** for neural nets. **Beta calibration** for probabilities squeezed near 0 or 1.
- Fit the calibrator on a held-out period that comes *after* model training (time-ordered, see [[Markets — Backtesting Without Fooling Yourself]]).

## Pitch in

- [x] ML: reliability-by-edge table on EPL holdout (Poisson − close) → [[Analysis — EPL Poisson Model and Benter Holdout]].
- [ ] ML: same plots for tennis backtest.
- [ ] Sports: pick the score states that matter (post-break, set point, tiebreak) for state-conditional calibration.

## Sources

- [Walsh & Joshi — Bath research portal](https://researchportal.bath.ac.uk/en/publications/machine-learning-for-sports-betting-should-model-selection-be-bas/) · [ML in sports betting review (arXiv 2410.21484)](https://arxiv.org/pdf/2410.21484) `[Benchmark]`

## Related

- **Summary:** [[State of — Sports Analytics]] · [[State of — Machine Learning]] · [[State of — ML and Sports Markets]]

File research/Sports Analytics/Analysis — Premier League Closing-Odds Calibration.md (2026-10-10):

---
type: research
status: answered
author: marc
date: 2026-10-08
tags: [sports-analytics, machine-learning, ml-and-sports-markets, market-analysis, calibration, football-data, datasets]
---

# Analysis — Premier League Closing-Odds Calibration

**TL;DR**
- First **reproduced** numbers in-repo: 3,800 EPL matches (2015–16 → 2024–25), Bet365 **closing** 1X2, stored as parquet.
- Closing line is **well calibrated** overall (log loss ≈ 0.557 on expanded 1X2 rows). Longshot **underdogs** win **slightly more** than priced (+0.17 pp) — weak reverse favourite-longshot, not a free lunch.
- Heavy favourites (80–90% implied) **underpriced** in this sample (+5 pp empirical vs implied) — check sample size (177 rows) before betting on it.

**Builds on:** [[Data — Open Sports Datasets Beyond Tennis]] · [[Markets — Calibration Beats Accuracy for Betting Models]] · [[Markets — Efficiency and Biases in Sports and Prediction Markets]]

## How to refresh

From repo root (see `analysis/README.md`):

```bash
cd analysis && source .venv/bin/activate
python scripts/run_epl_closing_odds_study.py
```

**Registered tables:** `analysis/data/catalog.parquet` → dataset id `epl_b365_closing_matches`

## Global scores (reproduced 2026-10-08)

| Metric | Value |
|---|---|
| Matches | 3,800 |
| Expanded outcome rows (H/D/A) | 11,400 |
| Log loss | 0.557 |
| Brier | 0.188 |

## Favourite vs underdog (closing line, per match)

| Bucket | n | Mean implied | Empirical win rate | Gap (emp − implied) |
|---|---:|---:|---:|---:|
| Closing favorite | 3,822 | 54.4% | 55.4% | +1.0 pp |
| Closing underdog (not longshot) | 1,553 | 27.8% | 27.8% | ~0 |
| Closing underdog **longshot** (<25% implied) | 2,392 | 16.0% | 16.1% | +0.2 pp |

Interpretation: classic **longshot bias** (longshots win *less* than priced) is **not** visible on EPL closers here. That matches “sharp closing line is hard to beat,” and it’s why this dataset is for **method practice** (calibration, Benter, Kelly) not for claiming a soccer edge.

## Reliability by implied-probability bin

| Bin | n | Mean implied | Empirical | Gap |
|---|---:|---:|---:|---:|
| 0.0–0.1 | 550 | 7.3% | 6.7% | −0.6 pp |
| 0.1–0.2 | 1,917 | 15.7% | 15.9% | +0.2 pp |
| 0.2–0.3 | 4,155 | 25.7% | 25.1% | −0.6 pp |
| 0.4–0.5 | 1,161 | 45.0% | 43.8% | −1.3 pp |
| 0.6–0.7 | 603 | 64.8% | 68.7% | +3.9 pp |
| 0.8–0.9 | 177 | 83.7% | 88.7% | +5.0 pp |

Full CSV: `analysis/outputs/tables/epl_b365_reliability_by_bin.csv`  
Figure: `analysis/outputs/figures/epl_b365_calibration_curve.png`

## Pitch in

- [ ] Sports: run the same pipeline on **Betfair closing** or Pinnacle if we add a source column.
- [x] ML: Poisson walk-forward + Benter holdout **2425** → [[Analysis — EPL Poisson Model and Benter Holdout]].
- [ ] Tennis: mirror script once Sackmann + Polymarket history land ([[Tennis — In-Play Market Research]] checklist §6).

## Related

- **Literature table (no download):** [[Analysis — Prediction Market Calibration (Literature Tables)]]
- **Summary:** [[State of — Sports Analytics]] · [[State of — ML and Sports Markets]]

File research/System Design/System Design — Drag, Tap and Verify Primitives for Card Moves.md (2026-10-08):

---
type: research
status: in-progress
author: marc
date: 2026-10-07
tags: [system-design, robotics, rl-and-simple-robots, card-games, gestures, gcode]
---

# System Design — Drag, Tap and Verify Primitives for Card Moves

**TL;DR**
- Card games need **three physical primitives**: `tap` (select, deal, buttons), `drag` (move a card or stack), and `wait_stable` (let animations finish).
- **Drag is the hard one:** the stylus must stay in contact through the whole path, start with a short hold so the app recognises a drag, and end with a dwell before lifting.
- Many card apps also support **tap-to-move**, which is far more reliable for a robot. Use it when available.

**Builds on:** [[Gantry — FluidNC Control Interface (Jogging, Soft Limits, Realtime)]], [[iOS Control — Exposing Device Controls to the Agent]], [[System Design — Card-Playing Gantry Rig Architecture]].

## Primitive definitions (screen px in, G-code out)

```
tap(x, y):        move_xy(x,y) → z_down → dwell(t_tap≈80–120 ms) → z_up
drag(path):       move_xy(p0) → z_down → dwell(t_hold≈150–300 ms)      # drag recognition
                  → for p in path: linear move (constant feed, no lift)
                  → dwell(t_drop≈100–200 ms) → z_up
wait_stable():    poll frames until 2 consecutive frames match (or timeout)
```

Timings are starting points, not measurements. Tune them with the bandit/BO loop ([[RL — Bandits and Bayesian Optimisation for Hardware Tuning]]).

## Making drags work on a gantry

- **Contact must be continuous.** Z pressure comes from a spring, so small surface height variations don't break contact. Lift-off mid-path cancels or misplaces the drag.
- **Use plain feed moves (`G1`) for the path, not jogs.** It's one continuous motion, with feed tuned so the app's drag tracking keeps up. Jogs (`$J=`) are for free moves between gestures.
- **Short path with a final settle:** go to the target's centre and drop. Apps usually snap the card to the pile, so precision only needs to be within the drop zone.
- **Stack moves** (drag a run of cards): grab the **top card of the run**, not the bottom. Check the app's convention once.
- **Fallback, tap-to-move:** a single tap auto-moves the card to its best destination in many apps. It's deterministic and much more robust than dragging. Prefer it whenever the game offers it.

## Verify after every primitive

| Primitive | Expected effect | Check |
|---|---|---|
| tap(card) | Card highlighted or auto-moved | Diff in the card's region within 1 s |
| drag(card → pile) | Card now on top of the target pile; source pile changed | State tracker predicts the new board; perception confirms |
| tap(button) | Screen or dialog changes | Template match on the expected next screen |

Retry policy: one retry with re-perceived coordinates → then reset to a known state → else stop and alert ([[System Design — Reliability, Error Recovery and Testing Harness]]).

## Measure

- Drag success rate vs feed speed, hold time and path length; tap success vs dwell.
- Fold the numbers into the actuator-noise model so emulator-trained policies expect real misses ([[RL — Emulator-First Training and Sim-to-Real for the Rig]]).

## Pitch in

- [ ] Robotics: implement `drag()` on the printer-gantry; sweep hold time 100–400 ms × feed 1,000–6,000 mm/min, 20 drags each; post a heatmap.

## Sources

1. [Grbl 1.1 jogging docs (mirror)](https://gitea.psi.ch/motion/ecmc_plugin_grbl/src/branch/master/doc/markdown/jogging.md) `[Documented]`
2. [TapsterBot Robot Framework keywords (tap, swipe, stress gestures)](https://github.com/pylapp/tapsterbot/wiki/07-%5C--Drive-the-robot:-Robot-Framework-keywords) `[Documented]`
3. [Tapster — robot manipulates phone (Tindie)](https://blog.tindie.com/2016/09/tapster-manipulates-phone-automatically) `[Community]`

## Related

- **Summary:** [[State of — System Design]] · [[State of — Robotics]] · [[State of — RL and Simple Robots]]
- **See also:** [[Touch Telemetry — Measuring What the Rig Emits]] · [[System Design — Bare-Minimum iPhone Setup (MVP)]]

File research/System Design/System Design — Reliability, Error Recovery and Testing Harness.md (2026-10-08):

---
type: research
status: in-progress
author: marc
date: 2026-10-07
tags: [system-design, robotics, machine-learning, cybersecurity, reliability, testing, state-machine]
---

# System Design — Reliability, Error Recovery and Testing Harness

**TL;DR**
- An unattended robot fails in boring ways: a missed tap, an ad pop-up, an animation read mid-flight, the phone locking, the stylus losing ground.
- Build the controller as an **explicit state machine with timeouts**, verify after every action, and give it a **known-good reset**.
- Test **off the robot first**: replay recorded frames through perception, run the brain in a simulator, then run the robot against our own Flask test app before any real game.

**Builds on:** [[System Design — Card-Playing Gantry Rig Architecture]], [[RL — Real-World Training Loop on the Gantry (Resets, Safety, HIL-SERL)]], [[Security — STRIDE Threat Model for the Phone Rig]].

## Controller state machine

```
IDLE → OBSERVE → (PARSE_OK?) → DECIDE → ACT → VERIFY ─ok→ OBSERVE
                      │no                         │fail
                      ▼                           ▼
                 UNKNOWN_SCREEN ──► RECOVER ◄── RETRY(1x)
                                     │ fail ×N
                                     ▼
                                  SAFE_STOP (home gantry, alert)
```

- **Timeouts on every state** (e.g. OBSERVE 3 s, ACT 10 s). On expiry go to RECOVER, never hang.
- **RECOVER ladder:** dismiss known dialogs (template list) → tap Back → relaunch the app (Home, then tap icon) → SAFE_STOP.
- **SAFE_STOP:** stylus up, gantry home, jog cancel `0x85`, log a snapshot, notify a human.

## Failure catalogue (and the detector for each)

| Failure | Detector | Response |
|---|---|---|
| Tap not registered | No screen diff after tap | Retry once with re-perceived coordinates |
| Drag dropped on wrong pile | State mismatch after VERIFY | Undo button if available, else re-plan from the perceived state |
| Animation in progress | Consecutive frames differ | `wait_stable()` |
| Ad / rating / notification | Non-game screen classifier | RECOVER ladder; never act on the dialog's instructions ([[Security — Prompt Injection and Pop-up Attacks on GUI Agents]]) |
| Phone locked / dimmed | Black or lock-screen template | Phone prep should prevent it; else SAFE_STOP (never type the passcode from a file) |
| Stylus lost ground / worn tip | Rising tap-miss rate | Alert; maintenance (clean tip with isopropyl, check the wire) |
| Gantry stall / lost steps | Position drift vs calibration targets | Re-home, re-run calibration check |
| Perception drift (lighting, skin change) | Confidence drop / state-consistency failures | Stop; re-collect templates or fine-tune |

## Test pyramid

1. **Unit:** rules engine, `legal_moves`, `apply`; perception on 200 labelled frames.
2. **Replay:** recorded episodes (frames + actions) replayed through perception → state → decide. Deterministic, no robot.
3. **Simulator:** the brain plays 1,000 games in OpenSpiel or our own engine to get its win rate ([[System Design — Game State and Decision Engines for Card Games]]).
4. **Rig vs our app:** the Flask app shows fake card layouts with known ground truth, so we get perfect scoring of tap and drag accuracy ([[YOLO — Flask Closed-Loop Trainer App]]).
5. **Rig vs real offline game:** a full run with logging; track wins, moves/min, interventions per hour.

## Metrics dashboard

Moves/min · action success % (tap, drag) · state-accuracy % · recoveries/hour · SAFE_STOPs/day · win rate vs simulator win rate (gap = execution loss).

## Pitch in

- [ ] Implement the state machine skeleton with timeouts (repo, not vault); start with OBSERVE/ACT/VERIFY on the Flask app.
- [ ] Build the non-game screen classifier (templates of common dialogs).

## Sources

1. [Grbl jog cancel and status (mirror)](https://gitea.psi.ch/motion/ecmc_plugin_grbl/src/branch/master/doc/markdown/jogging.md) `[Documented]`
2. [Zhang et al. — pop-up attacks on computer agents (ACL 2025)](https://aclanthology.org/2025.acl-long.411) `[Benchmark]`
3. [Cowling et al. — ISMCTS](https://eprints.whiterose.ac.uk/75048) `[Benchmark]`

## Related

- **Summary:** [[State of — System Design]] · [[State of — Robotics]] · [[State of — Machine Learning]] · [[State of — Cybersecurity]]
- **See also:** [[System Design — Drag, Tap and Verify Primitives for Card Moves]] · [[System Design — Reading Cards from the Screen]]

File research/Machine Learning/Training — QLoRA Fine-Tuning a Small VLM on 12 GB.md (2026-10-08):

---
type: research
status: answered
author: marc
date: 2026-10-07
tags: [machine-learning, rl-and-simple-robots, qlora, lora, unsloth, vlm, fine-tuning, gpu]
---

# Training — QLoRA Fine-Tuning a Small VLM on 12 GB

**TL;DR**
- The ML plan calls for fine-tuning a ~3B grounding VLM (ZonUI-3B-class) on our captures, using the **RTX 3060 12 GB**.
- **QLoRA** (4-bit base + LoRA adapters) cuts weight memory ~75%. Unsloth supports Qwen2.5-VL, including vision GRPO.
- No source confirms Qwen2.5-VL-3B QLoRA *on 12 GB* specifically, so treat it as **plausible but untested**. Image tokens are the main memory risk.

**Builds on:** [[Agents — VLM GUI Agents and Vision Grounding Survey]] (ZonUI-3B fits a single 4090 with 24k samples), [[YOLO — Training on Different Hardware]], [[RL — GRPO in Practice on Small GPUs]].

## What the sources support

- QLoRA quantises the base to 4-bit before attaching adapters, "cutting memory by roughly 75%". Guide estimate ~5 GB for 7B *text* models [1].
- Unsloth added **vision RL (GRPO) for Qwen2.5-VL** (Aug 2025), with the 7B example on a free Colab T4 and a "90% less VRAM than FA2 setups" vendor claim [2].
- Current Unsloth VLM guides default to `max_seq_length 2048`, per-device batch 4, with newer small VLMs (e.g. Qwen3.5-2B) on 24 GB [3][4].
- Consumer-GPU guides claim 7B text QLoRA in 2–4 h on 12 GB (secondary source; not VLM) [5].

## Recipe to try (in order of memory relief)

1. Base: 4-bit Qwen2.5-VL-3B-Instruct (Unsloth notebook) [2].
2. **batch 1 + gradient accumulation 8–16**; gradient checkpointing on.
3. **Cap the image resolution.** Our screenshots can be downscaled or cropped to the region of interest, and image tokens dominate sequence length.
4. LoRA r = 16 on attention + MLP; freeze the vision tower first, unfreeze later if grounding plateaus.
5. **Short targets:** the answer is a JSON action or a point (x, y), so `max_seq_length` mostly goes to image tokens.
6. Watch peak VRAM over the first 20 steps; if it OOMs, reduce image size before anything else [4].

## Data format

`(image, instruction) → {"action": "tap", "x": 0.42, "y": 0.77}` in normalised coordinates, so data from phones of different sizes can be mixed. Source: Flask episodes, plus emulator traces later ([[RL — Imitation Learning from Logged Taps (BC, ACT, LeRobot)]]).

## Evaluate like ScreenSpot

Point-in-box accuracy on a held-out set **of our own camera or capture images**, split by element size. Camera photos are harder than screenshots and there's no published benchmark for that gap.

## Pitch in

- [ ] ML: run the recipe on 2k Flask samples; post peak VRAM, step time and point-in-box accuracy.

## Sources

1. [LoRA training on consumer hardware (PDF)](https://insiderllm.com/pdfs/lora-training-consumer-hardware.pdf) `[Community]`
2. [Unsloth — vision RL](https://unsloth.ai/blog/vision-rl) `[Documented]` (vendor)
3. [Intel — VLM fine-tuning with Unsloth](https://docs.openedgeplatform.intel.com/2026.2/edge-ai-suites/ai-suite-manufacturing/industrial-edge-insights-multimodal/how-to-guides/how-to-fine-tune-vlm.html) `[Documented]`
4. [LearnOpenCV — Unsloth vision fine-tuning guide](https://learnopencv.com/unsloth-guide-efficient-llm-fine-tuning/) `[Community]`
5. [MachineLearningPlus — Unsloth fine-tuning](https://machinelearningplus.com/gen-ai/unsloth-fine-tuning/) `[Community]`

## Related

- **Summary:** [[State of — Machine Learning]] · [[State of — RL and Simple Robots]]

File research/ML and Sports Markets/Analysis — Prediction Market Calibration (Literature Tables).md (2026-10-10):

---
type: research
status: answered
author: marc
date: 2026-10-08
tags: [sports-analytics, machine-learning, ml-and-sports-markets, market-analysis, polymarket, kalshi, calibration]
---

# Analysis — Prediction Market Calibration (Literature Tables)

**TL;DR**
- Vault had **qualitative** bias notes; this note pins **numbers** from recent large-sample papers and stores them in `literature/market_benchmarks.parquet` for side-by-side compares with our own runs.
- **Politics** on Polymarket/Kalshi: prices **compressed toward 50%** (logistic recalibration slope ≈ **1.45** on Polymarket politics mean) — do **not** read 70¢ as 70% for politics.
- **Sports** on prediction markets: near **calibrated** at short horizons; **trade-size** distortion that hits politics on Kalshi is **~null** for sports (Δ slope ≈ **0.07**, CI crosses zero).
- **Tennis fade anchor** unchanged: Brown in-play mispricing **~5.3%** average, **~10×** pre-match; break → set **~70–75%**.

**Builds on:** [[Markets — Efficiency and Biases in Sports and Prediction Markets]] · [[Tennis — In-Play Market Research]]

## Pandas registry

| dataset_id | File | Purpose |
|---|---|---|
| `literature_market_benchmarks` | `analysis/data/literature/market_benchmarks.parquet` | Paper benchmarks keyed by `benchmark_id` |
| `epl_b365_closing_matches` | `analysis/data/football/epl_b365_closing_matches.parquet` | Our reproduced sports-book calibration ([[Analysis — Premier League Closing-Odds Calibration]]) |

```bash
python analysis/scripts/compare_datasets.py --list
```

## Benchmark table (curated from sources)

| benchmark_id | Domain | Metric | Value | Notes |
|---|---|---|---|---|
| brown_2014_inplay_mispricing_avg | tennis in-play | avg price vs fair | **5.3%** | ~10× pre-match |
| brown_2014_break_to_set_conversion | tennis in-play | break → set win | **70–75%** | fade structural prior |
| walsh_joshi_2024_roi_calibration_vs_accuracy | NBA betting | ROI calibration vs accuracy | **+34.7%** vs **−35.2%** | model *selection* not sizing |
| arxiv_2602_politics_calibration_slope | PM politics | recalibration slope | **1.45** | >1 ⇒ underconfident / compressed |
| arxiv_2602_sports_trade_size_gap | PM sports | large−small trade Δ slope | **0.07** [−0.07, 0.26] | unlike politics whales on Kalshi |
| reichenbach_2026_polymarket_sports_vs_books | Polymarket sports | vs book accuracy | **≈ pro books** | live distortions still possible |

## What this means for our graph / strategy

1. **Polymarket tennis in-play** — treat [[Markets — Cross-Venue Prices - Polymarket, Kalshi and Betfair]] as mandatory: sports *category* may be calibrated on average, but **live** paths can overshoot (Reichenbach 2026; Brown 2014 for tennis specifically).
2. **Politics-style “pull toward 50%”** — do **not** import into tennis without measuring ([[Markets — Efficiency and Biases in Sports and Prediction Markets]] already warned on this).
3. **Next empirical node** — break-event study linking Brown overshoot to Polymarket CLOB history (checklist in [[Tennis — In-Play Market Research]] §6).

## Reproduce / extend literature rows

Edit `analysis/markets_research/literature_benchmarks.py`, then:

```bash
python analysis/scripts/run_epl_closing_odds_study.py
```

(That script rewrites the literature parquet even if you skip football download.)

## Sources

- [Decomposing Crowd Wisdom (arXiv 2602.19520)](https://arxiv.org/abs/2602.19520) · [Code snapshot notes](https://github.com/namanhzz/prediction-market-calibration) `[Benchmark]`
- [When Can Prediction Market Prices Be Trusted? (SSRN 7552098)](https://papers.ssrn.com/sol3/papers.cfm?abstract_id=7552098) `[Benchmark]`
- Brown 2014 · Walsh & Joshi 2024 — see vault notes above `[Benchmark]`

## Related

- **Summary:** [[State of — ML and Sports Markets]] · [[State of — Sports Analytics]]

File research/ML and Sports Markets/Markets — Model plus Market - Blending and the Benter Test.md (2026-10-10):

---
type: research
status: answered
author: marc
date: 2026-10-07
tags: [sports-analytics, machine-learning, ml-and-sports-markets, model-blending, benter, market-prior, residual-modeling, logistic-regression]
---

# Markets — Model plus Market: Blending and the Benter Test

**TL;DR**
- Don't try to beat the market *instead of* using it. **Use it as the prior and model what it misses.**
- Benter's second-stage logit does this: regress outcomes on logit(model) and logit(market). If the model's coefficient is significant, it adds information; the blended probability is what you bet.
- For the tennis fade, go one step further and **target the market's overreaction directly** as the residual.

**Builds on:** [[Markets — Calibration Beats Accuracy for Betting Models]] (shrink toward the market) and [[Markets — Efficiency and Biases in Sports and Prediction Markets]].

## The Benter second stage

**logit(p_final) = α · logit(p_model) + β · logit(p_market)**, fitted on held-out outcomes.

- In Benter's 1994 horse-racing work (2,313 races), the fundamental model alone had pseudo-R² .1016, about the same as a tipster tally (.1014). Combined with the public odds, the model **added +.0090** while the tipster added +.0002. A model can look no better alone yet still carry real *extra* information. `[Community]` (secondary source; check the original paper)
- What the test tells you:
  - α ≈ 0: the model adds nothing over the market. Stop.
  - α > 0, β > 0: bet on p_final, not p_model.
  - β > 1 or < 1: the market itself is mis-scaled (FLB-type bias). Worth knowing on its own.

## Other blending methods

- **Hierarchical Bayesian** (Egidi, Pauli & Torelli 2018, football): scoring rates are convex combinations of historical-data parameters and odds-implied parameters inside the model. `[Benchmark]`
- **Shrinking toward climatology or market** also improves calibration and reliability, as seen in football shot models where blending beat Platt scaling. `[Benchmark]`

## The residual model for tennis in-play

Instead of predicting the match winner, predict **where the market will be (or the outcome) relative to its current price**:

- **Target:** y = outcome − p_market(t), or the price change over the next N minutes.
- **Features:** p_market(t); the Markov fair value from the score; *market − Markov* (the overreaction gap); time since the break; pressure-point flags and clutch profile ([[Tennis — Player and Matchup Modeling]]); fatigue signals from the tennis checklist; book imbalance.
- **Why:** the model only has to learn *when the market is wrong*, which is a much smaller and better-posed problem than tennis win probability from scratch. It plugs straight into the Benter test.

## Pitch in

- [x] ML: Benter on walk-forward Poisson vs Bet365 close — **2425 holdout**, α≈−0.12 (NS), market wins → [[Analysis — EPL Poisson Model and Benter Holdout]].
- [ ] ML: run the Benter test on the **tennis Markov** model against Betfair closing odds over the backtest set; post α, β and the confidence intervals.
- [ ] Sports: list candidate residual features from the player-modeling note that are available live.

## Sources

- [Benter's second-stage test explained](https://oddspapi.io/blog/?p=3174) `[Community]`
- [Egidi et al. — combining historical data and odds (arXiv 1802.08848)](https://arxiv.org/pdf/1802.08848) · [Statistical Modelling 18(5-6)](https://statmod.org/smij/Vol18/Iss5-6/Egidi/Abstract.html) · [Probabilistic shot-success model (arXiv 2101.02104)](https://arxiv.org/pdf/2101.02104) `[Benchmark]`

## Related

- **Summary:** [[State of — Sports Analytics]] · [[State of — Machine Learning]] · [[State of — ML and Sports Markets]]

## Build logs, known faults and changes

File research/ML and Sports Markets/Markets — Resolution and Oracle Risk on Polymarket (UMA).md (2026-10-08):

---
type: research
status: answered
author: marc
date: 2026-10-07
tags: [sports-analytics, cybersecurity, ml-and-sports-markets, polymarket, uma, oracle, resolution-risk]
---

# Markets — Resolution and Oracle Risk on Polymarket (UMA)

**TL;DR**
- Polymarket outcomes are settled by **UMA's optimistic oracle**. Someone proposes an answer with a **$750 bond**; if nobody disputes within the window it's final; disputes go to a **UMA token-holder vote**.
- It usually works, but there are documented failures: a ~$7M Ukraine-minerals market resolved YES with no official deal (whale-influence suspected), and a NASCAR dispute ballooned to $60k of bonds on a $10k market.
- For tennis, resolution risk is low (results are unambiguous) **except** for retirements, walkovers and suspended matches. Read each market's rules.

**Builds on:** [[Markets — Polymarket Order Book, Fees and Execution]]. Execution risk is one layer; this is settlement risk.

## How settlement works

- **Propose:** stake a $750 USDC.e bond on an outcome [1].
- **Challenge window:** if no dispute, it settles automatically; the loser of any dispute forfeits their bond [1].
- **Dispute → vote:** UMA holders decide [1]. Settlement takes at least ~2 hours if uncontested, days to weeks if escalated [2].

## Documented failure modes

| Case | What happened | Lesson |
|---|---|---|
| **NASCAR (July)** | A trader posted 40 proposals (one per driver) at $750 each; all 40 were disputed → $60k staked on a $10k market. Voters ruled "Too Early" although UMA docs don't require waiting for inspection [1] | Rules about *timing* are ambiguous |
| **Ukraine minerals (~$7M)** | Resolved YES although reportedly no official agreement existed; a "UMA whale" was suspected [1][3] | Voter concentration; one report claims whales hold up to 7.5M of 20M staked UMA (unverified) [1] |
| **Ambiguous wording** | Holders with positions interpret criteria in their own favour [1] | Wording risk is the biggest driver |

## Cross-venue contrast

Kalshi names **source agencies** in contract terms filed with the CFTC and verifies within hours to ~1 day. The same real-world event can resolve **differently** on the two venues because of wording and timing differences [2][4]. See [[Markets — Cross-Venue Prices - Polymarket, Kalshi and Betfair]].

## Tennis-specific checks (do before trading any market)

- What happens on **retirement mid-match**? (Sportsbooks vary: some void, some settle on advancement. Read the market text.)
- Walkover before the start, a suspended match finishing the next day, a venue change: does the market's end date allow for it?
- Model **resolution risk as a small probability of a 50/50 or void outcome** in the EV calculation for in-play positions held into those edge cases.

## Pitch in

- [ ] Sports: collect the rules text from 10 Polymarket tennis markets; tabulate the retirement and walkover handling.
- [ ] Security: monitor UMA disputes on any market we hold (alert on proposal/dispute events).

## Sources

1. [NexusFi — Polymarket/UMA oracle dispute](https://nexusfi.com/a/prediction-markets/polymarket-uma-oracle-dispute) · [CryptoSlate — NASCAR $60k dispute](https://cryptoslate.com/polymarket-10k-bet-on-nascar-race-turns-to-60k-dispute-following-zelensky-controversy/) · [pm.wiki — UMA](https://pm.wiki/it/data/glossary/uma) `[Community]`
2. [DeFi Rate — how Kalshi and Polymarket settle](https://defirate.com/?p=5575) `[Community]`
3. [Coin360 — oracle vote manipulation](https://coin360.com/news/polymarket-oracle-vote-manipulation-scandal) `[Community]`
4. [Orrery — Polymarket vs Kalshi resolution rules](https://orrery.me/learn/polymarket-vs-kalshi-resolution-rules) `[Community]`

## Related

- **Summary:** [[State of — Sports Analytics]] · [[State of — Cybersecurity]] · [[State of — ML and Sports Markets]]

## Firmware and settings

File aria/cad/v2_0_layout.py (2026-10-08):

"""v2 LAYOUT (concept, view-only): CoreXY gantry over a row of 4 iPhones.

See docs/hardware-concept-v2.md. Real envelope dimensions, placeholder shapes, colors = real materials.

How it moves (CoreXY): both motors are FIXED at the +X end. Two belts (A low, B high) each run
toolhead -> bridge end idler -> along a side -> around their motor pulley -> back along the outside
-> across the -X end -> along the other side -> other bridge end idler -> back to the toolhead.
  motor A and B turn the SAME way      -> bridge moves along X (across the phones)
  motor A and B turn OPPOSITE ways     -> toolhead moves along Y on the bridge rail (down each phone)
Each pulley is wrapped 180 deg (motors) or 90 deg (idlers): the two strands leaving a pulley are
one pitch-diameter apart.

Frame: X = long axis (row of phones), Y = front/back, Z = up. Origin = base center.
Run:  ../.venv/Scripts/python.exe v2_0_layout.py   -> v2_0_layout.step / .stl
"""
from build123d import *

# ---------------- envelope (mm) ----------------
BASE_Y, BASE_T = 320, 3                   # base: 3 mm aluminium plate, laser-cut at JLCCNC (slotted holes); X derived below
FEET = 3
PITCH, N_PHONES = 95, 2                   # phones in the row: change this and the frame resizes
PHONE = (77.6, 163.0, 8.25)               # iPhone Pro Max body (worst case)
TRAY_T = 2
RAIL_Y = 105                              # long rails at y = +/- this
RISER = (20, 10)                          # aluminium flat bar 20 wide x 10 tall under each long rail
BRIDGE_RAIL_L, BRIDGE_L = 230, 240
STOCK_RAILS = (200, 215, 230, 250, 260, 280, 300, 320, 330, 350, 360, 380, 400, 420, 440, 450, 470, 490, 500)
MGN9_RAIL_W, MGN9_RAIL_H = 9, 6.5
MGN9H_L, MGN9H_W, MGN9H_TOP = 39.9, 20, 10   # carriage length, width, top above rail base
BRIDGE_W = BRIDGE_H = 20                  # 2020 extrusion
MOTOR = (42.3, 42.3, 23)                  # NEMA 17 pancake
MOTOR_B_RISE = 8                          # motor B sits on a spacer so its pulley lines up with belt B
GT2_PD = 12.73                            # 20T GT2 pitch diameter
R = GT2_PD / 2
FLANGE_R, PULLEY_H = 8, 8                 # pulley/idler flange radius, toothed-section height
BELT_W, BELT_T = 6, 1.5
LIFT = 3                                  # stylus tip clearance above glass when up
CAP_T = 3                                 # top plates that clamp idler bolts from above (double support)

glass_z = BASE_T + TRAY_T + PHONE[2]
rail_base_z = BASE_T + RISER[1]
bridge_z0 = rail_base_z + MGN9H_TOP
bridge_z1 = bridge_z0 + BRIDGE_H
ZA, ZB = bridge_z0 + 8, bridge_z0 + 16    # belt plane centers (A low, B high), both inside bridge height

# CoreXY belt geometry
YI = 125.0                                # inner strand: bridge-end idler -> its motor
YO = YI + GT2_PD                          # outer strand: motor -> far corner (one pitch diameter out)
YC = (YI + YO) / 2                        # motor pulley / corner idler centers
# frame sized from the phone count: stylus reach -> long-rail length (stock size, +10 mm margin) -> motors -> base
REACH = (N_PHONES - 1) / 2 * PITCH + PHONE[0] / 2          # stylus half-travel along X
LONG_RAIL_L = min(L for L in STOCK_RAILS if L >= 2 * (REACH + MGN9H_L / 2) + 10)
XM = LONG_RAIL_L / 2 + 9 + MOTOR[0] / 2   # motor pulleys at +XM (motors clear the rail risers), corner idlers at -XM
BASE_X = 2 * (XM + MOTOR[0] / 2 + 4)
X_BACK = 19.0                             # belts run along the BACK of the bridge at x = bridge + X_BACK
CLAMP_HALF = 15                           # toolhead belt clamp half-length (belts end on its faces)

STYLUS_DX = -(BRIDGE_W / 2 + MGN9_RAIL_H + 21)   # stylus tip vs bridge centerline (toolhead hangs in front)
xs = [(i - (N_PHONES - 1) / 2) * PITCH + STYLUS_DX for i in range(N_PHONES)]  # row shifted -> travel centered

# ---------------- colors = real materials ----------------
C = dict(
    plate=Color(0.70, 0.71, 0.74), rubber=Color(0.07, 0.07, 0.07), cf=Color(0.22, 0.22, 0.24),
    tpu=Color(0.12, 0.12, 0.13), alu=Color(0.83, 0.84, 0.87), steel=Color(0.60, 0.61, 0.64),
    stator=Color(0.10, 0.10, 0.11), phone=Color(0.30, 0.30, 0.33), glass=Color(0.04, 0.05, 0.09),
    servo=Color(0.08, 0.08, 0.09), brass=Color(0.80, 0.62, 0.25), belt=Color(0.03, 0.03, 0.03))

static, phones = [], []
def add(lst, shape, color, label):
    shape.color, shape.label = C[color], label
    lst.append(shape)
    return shape

def box(x, y, z, sx, sy, sz):                    # centered box
    return Pos(x, y, z) * Box(sx, sy, sz)

def cyl(x, y, z0, z1, r):                        # vertical cylinder from z0 to z1
    return Pos(x, y, (z0 + z1) / 2) * Cylinder(radius=r, height=z1 - z0)

def belt_x(lst, y, x0, x1, z):                   # belt strand running along X
    if x1 - x0 > 0.5:
        add(lst, box((x0 + x1) / 2, y, z, x1 - x0, BELT_T, BELT_W), "belt", "GT2 belt")

def belt_y(lst, x, y0, y1, z):                   # belt strand running along Y
    if y1 - y0 > 0.5:
        add(lst, box(x, (y0 + y1) / 2, z, BELT_T, y1 - y0, BELT_W), "belt", "GT2 belt")

def pulley(lst, x, y, z, label, color="alu"):     # 20T pulley/idler: toothed body + two flanges
    add(lst, cyl(x, y, z - PULLEY_H / 2, z + PULLEY_H / 2, R), color, label)
    for s in (-1, 1):
        add(lst, cyl(x, y, z + s * (PULLEY_H / 2) - 0.5, z + s * (PULLEY_H / 2) + 0.5, FLANGE_R), color, label + " flange")

# ---------------- static: base, slots, rails ----------------
add(static, box(0, 0, BASE_T / 2, BASE_X, BASE_Y, BASE_T), "plate", "base plate (3 mm aluminium, JLCCNC)")
for sx in (-1, 0, 1):                              # 6 feet: middle pair stops the thin plate sagging
    for sy in (-1, 1):
        add(static, cyl(sx * (BASE_X / 2 - 20), sy * (BASE_Y / 2 - 20), -FEET, 0, 10), "rubber", "foot (black TPU)")

for i, x in enumerate(xs):
    add(static, box(x, 0, BASE_T + TRAY_T / 2, PITCH - 5, PHONE[1] + 12, TRAY_T), "cf", f"slot {i+1} tray (CF-PETG)")
    for sx in (-1, 1):
        for sy in (-1, 1):
            add(static, box(x + sx * (PHONE[0] / 2 + 2.5), sy * (PHONE[1] / 2 + 2.5), BASE_T + TRAY_T + 3, 5, 5, 6),
                "tpu", f"slot {i+1} corner pad (TPU)")
    z0 = BASE_T + TRAY_T
    add(phones, box(x, 0, z0 + (PHONE[2] - 0.3) / 2, PHONE[0], PHONE[1], PHONE[2] - 0.3), "phone", f"iPhone {i+1}")
    add(phones, box(x, 0, glass_z - 0.15, PHONE[0] - 2, PHONE[1] - 2, 0.3), "glass", f"iPhone {i+1} screen")

for sy in (-1, 1):
    y = sy * RAIL_Y
    add(static, box(0, y, BASE_T + RISER[1] / 2, LONG_RAIL_L + 10, RISER[0], RISER[1]), "alu", "rail riser (alu flat bar 20x10)")
    add(static, box(0, y, rail_base_z + MGN9_RAIL_H / 2, LONG_RAIL_L, MGN9_RAIL_W, MGN9_RAIL_H), "steel", f"MGN9 rail {LONG_RAIL_L}")

# ---------------- static: motors (+X end) and corner idlers (-X end) ----------------
for name, sy, zp, rise in (("A", 1, ZA, 0), ("B", -1, ZB, MOTOR_B_RISE)):
    my = sy * YC
    z_bot = BASE_T + rise
    if rise:
        add(static, box(XM, my, BASE_T + rise / 2, MOTOR[0], MOTOR[1], rise), "cf", f"motor {name} spacer (CF-PETG)")
    add(static, box(XM, my, z_bot + (MOTOR[2] - 3) / 2, MOTOR[0], MOTOR[1], MOTOR[2] - 3), "stator", f"NEMA17 pancake {name}")
    add(static, box(XM, my, z_bot + MOTOR[2] - 1.5, MOTOR[0], MOTOR[1], 3), "alu", f"NEMA17 {name} end cap")
    add(static, cyl(XM, my, z_bot + MOTOR[2], zp - PULLEY_H / 2, 6.5), "alu", f"pulley {name} hub")
    # motor clamp: two bars over the face-hole pairs (belts + pulley pass between them), legs to the base
    top = z_bot + MOTOR[2]
    for side in (-1, 1):
        by = my + side * 15.5
        add(static, box(XM + 2, by, top + 1.5, 46, 8, 3), "cf", f"motor {name} clamp bar (CF-PETG)")
        add(static, box(XM + 23, by, BASE_T + (top + 3 - BASE_T) / 2, 4, 8, top + 3 - BASE_T), "cf",
            f"motor {name} clamp leg (CF-PETG)")
    pulley(static, XM, my, zp, f"GT2 20T pulley {name} (motor)")

for sy in (-1, 1):
    cy = sy * YC
    add(static, box(-XM, cy, BASE_T + (ZA - PULLEY_H / 2 - 1 - BASE_T) / 2, 16, 16, ZA - PULLEY_H / 2 - 1 - BASE_T),
        "cf", "corner idler post (CF-PETG)")
    cap_z0 = ZB + PULLEY_H / 2 + 1
    add(static, cyl(-XM, cy, BASE_T, cap_z0 + CAP_T, 1.5), "steel", "M3 idler bolt (clamped both ends)")
    add(static, box(-XM - 4, cy, cap_z0 + CAP_T / 2, 24, 20, CAP_T), "cf", "corner idler top plate (CF-PETG)")
    add(static, box(-XM - 14.5, cy, BASE_T + (cap_z0 + CAP_T - BASE_T) / 2, 3, 20, cap_z0 + CAP_T - BASE_T), "cf",
        "corner idler side wall (CF-PETG, outside the belt)")
    pulley(static, -XM, cy, ZA, "idler A (corner)")
    pulley(static, -XM, cy, ZB, "idler B (corner)")

# ---------------- moving: bridge, toolhead, bridge-end idlers, belts ----------------
def gantry(bx, ty):
    """bx = bridge centerline X, ty = toolhead (= stylus) Y."""
    p = []
    x0 = bx + X_BACK                                   # belt line behind the bridge
    # long-rail carriages + bridge + its rail
    for sy in (-1, 1):
        add(p, box(bx, sy * RAIL_Y, rail_base_z + 1.5 + (MGN9H_TOP - 1.5) / 2, MGN9H_L, MGN9H_W, MGN9H_TOP - 1.5),
            "steel", "MGN9H carriage")
    add(p, box(bx, 0, (bridge_z0 + bridge_z1) / 2, BRIDGE_W, BRIDGE_L, BRIDGE_H), "alu", "bridge (2020 extrusion)")
    rail_x = bx - BRIDGE_W / 2 - MGN9_RAIL_H / 2
    add(p, box(rail_x, 0, (bridge_z0 + bridge_z1) / 2, MGN9_RAIL_H, BRIDGE_RAIL_L, MGN9_RAIL_W), "steel",
        f"MGN9 rail {BRIDGE_RAIL_L} (bridge)")
    # bridge end blocks carry the 4 bridge-end idlers (one per belt per end)
    for sy in (-1, 1):
        add(p, box(bx + 6.5, sy * 124.5, bridge_z0 + 1.5, 53, 33, 3), "cf", "bridge end block (CF-PETG)")
        cz0 = ZB + PULLEY_H / 2 + 1                    # top plate rests on the bridge via a 1 mm spacer
        add(p, box(bx + 12, sy * 125, cz0 + CAP_T / 2, 44, 32, CAP_T), "cf", "bridge end top plate (CF-PETG)")
        add(p, box(bx, sy * 115, (bridge_z1 + cz0) / 2, BRIDGE_W, 10, cz0 - bridge_z1), "cf", "top plate spacer")
    for x, y, z, lab in ((x0 + R, YI - R, ZA, "A+"), (x0 - R, YO - R, ZB, "B+"),
                         (x0 - R, -(YO - R), ZA, "A-"), (x0 + R, -(YI - R), ZB, "B-")):
        add(p, cyl(x, y, bridge_z0 + 3, ZB + PULLEY_H / 2 + 1 + CAP_T, 1.5), "steel", "M3 idler bolt (clamped both ends)")
        pulley(p, x, y, z, f"idler {lab} (bridge end)")
    # toolhead: carriage on the bridge rail, plate, servo, lever, sprung stylus, belt clamp
    fx = bx - BRIDGE_W / 2 - MGN9_RAIL_H               # front face of the bridge rail
    add(p, box(fx - 5, ty, (bridge_z0 + bridge_z1) / 2, 10, MGN9H_L, MGN9H_W), "steel", "MGN9H carriage (toolhead)")
    plate_z0 = glass_z + 7
    add(p, box(fx - 12.5, ty, (plate_z0 + bridge_z1) / 2, 5, 40, bridge_z1 - plate_z0), "cf", "toolhead plate (CF-PETG)")
    add(p, box(fx - 26, ty + 17.5, bridge_z1 - 6, 22, 23, 12), "servo", "MG90S servo (lying flat)")
    sx_, top = fx - 21, plate_z0 + 14
    add(p, box(sx_, ty + 4, top + 2, 10, 26, 4), "cf", "tap lever (CF-PETG)")
    add(p, cyl(sx_, ty, top - 8, top, 5), "cf", "stylus sleeve, spring inside (CF-PETG)")
    tip_z = glass_z + LIFT
    add(p, cyl(sx_, ty, tip_z + 3, top - 8, 2.5), "brass", "stylus barrel (brass tube, grounded)")
    add(p, cyl(sx_, ty, tip_z, tip_z + 3, 3), "rubber", "conductive stylus tip")
    add(p, box((fx - 15 + x0 + 7) / 2, ty, plate_z0 + 1.5, x0 + 7 - (fx - 15), 2 * CLAMP_HALF, 3), "cf",
        "toolhead under-bridge bracket (CF-PETG)")
    add(p, box(x0 + 2, ty, (plate_z0 + bridge_z1) / 2, 6, 2 * CLAMP_HALF, bridge_z1 - plate_z0), "cf",
        "belt clamp block (CF-PETG)")
    # belt A (low plane): toolhead -> A+ -> motor A -> outside -> -X end -> -Y side -> A- -> toolhead
    belt_y(p, x0, ty + CLAMP_HALF, YI - R, ZA)
    belt_x(p, YI, x0 + R, XM, ZA)
    belt_x(p, YO, -XM, XM, ZA)
    belt_y(p, -XM - R, -YC, YC, ZA)
    belt_x(p, -YO, -XM, x0 - R, ZA)
    belt_y(p, x0, -(YO - R), ty - CLAMP_HALF, ZA)
    # belt B (high plane): mirror image in Y
    belt_y(p, x0, -(YI - R), ty - CLAMP_HALF, ZB)
    belt_x(p, -YI, x0 + R, XM, ZB)
    belt_x(p, -YO, -XM, XM, ZB)
    belt_y(p, -XM - R, -YC, YC, ZB)
    belt_x(p, YO, -XM, x0 - R, ZB)
    belt_y(p, x0, ty + CLAMP_HALF, YO - R, ZB)
    return p

def gantry_at(x, y):                                   # place everything so the STYLUS TIP is over (x, y)
    return gantry(x - STYLUS_DX, y)

def travel_ok(x, y):
    bx = x - STYLUS_DX
    return abs(bx) + MGN9H_L / 2 <= LONG_RAIL_L / 2 and abs(y) + MGN9H_L / 2 <= BRIDGE_RAIL_L / 2

def clash(a_list, b_list):
    hits = []
    for a in a_list:
        for b in b_list:
            intended = (("MGN9H" in a.label and "rail" in b.label)          # carriage rides its rail
                        or ("belt" in a.label and ("pulley" in b.label or "idler" in b.label)))
            if not intended and (a & b).volume > 1e-3:
                hits.append((a.label, b.label))
    return hits

moving = gantry_at(xs[1], 20)                          # preview: stylus over phone 2

if __name__ == "__main__":
    corners = [(x + dx, dy) for x in xs for dx in (-PHONE[0] / 2, PHONE[0] / 2) for dy in (-PHONE[1] / 2, PHONE[1] / 2)]
    off_rail = [c for c in corners if not travel_ok(*c)]
    bad = []
    for c in corners:
        bad += clash(gantry_at(*c), phones + static)
    all_parts = static + moving + phones
    top = max(p.bounding_box().max.Z for p in all_parts)
    print(f"glass z {glass_z:.1f} | bridge underside {bridge_z0:.1f} | belt planes A {ZA} B {ZB} | top {top:.1f}")
    print(f"overall height incl. feet {top + FEET:.1f} mm | footprint {BASE_X} x {BASE_Y} mm")
    print("corners the carriages can't reach:", off_rail or "none")
    print(f"clashes with stylus at all {len(corners)} screen corners:", sorted(set(bad)) or "none")
    asm = Compound(children=all_parts, label="iPhone-Ian v2 layout")
    export_step(asm, "v2_0_layout.step")
    export_stl(asm, "v2_0_layout.stl")
    print("exported v2_0_layout.step / .stl with", len(all_parts), "components")

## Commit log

2026-09-05 Set Instructables 'Screen Tapping Robot' as mechanical design source of truth
    - Stored link in specs/01-hardware.md as the current design SoT (3D-printed
    Cartesian XY gantry, NEMA 17 + lead screw + dual 8mm precision shafts).
    - Demoted Tappy to a prior-art/lessons reference.
    - Marked the Cartesian-gantry reference-build research gap as resolved
    (charter Phase 0, research/README).
    - Left TODOs to extract Y-axis/Z/controller/BOM/STLs from the build page.
2026-09-05 Add reusable-parts & resources research (CAD, mechanics, firmware, CV, grounding models)
    In-depth pass on off-the-shelf ecosystems to reuse per layer:
    - CAD/model libraries (FreeCAD/OpenSCAD, Printables/GrabCAD, McMaster/Misumi)
    - Mechanics: OpenBuilds V-slot/ACRO, openBrushograph, CNC pen-plotter repos
    - Firmware: GRBL / FluidNC + servo-Z pen forks (= our tap)
    - Whole-robot precedent: Tapsterbot + BrainyBot (CV taps phone to play games)
    - Host: Python pyserial G-code streamers, UGS/bCNC/gSender
    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
2026-09-05 Split research into two specs (hardware vs firmware/software/ML); add Tapster lineage + deterministic control
    - specs/01-hardware.md: comprehensive HARDWARE spec with full CAD library (all user-provided links categorized + cited), mechanics reuse, tap options, BOM, citations.
    - Added Tapster design-lineage section (Push Button Robot, Sidekick two-arm, Valet Pi-based, BitBeamBot) with policy to borrow their open designs as much as possible.
    - specs/02-firmware-and-software.md: comprehensive FIRMWARE+SOFTWARE+ML spec; three firmware routes (GRBL/FluidNC, Firmata, custom), Tapster host-stack reuse, motor/servo/stepper libs (AccelStepper/S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
2026-09-05 Add DEVELOPMENT.md staged build pipeline
    Refines the user's 4-stage plan: agrees on backbone (mechanics -> deterministic control -> vision -> autonomy), adds Stage 0 fail-fast touch/grounding test, makes calibration explicit, splits final stage into autonomy vs credentials/security. Each stage has goal, build/reuse, Definition of Done, key risk, and one runnable check. Linked from README.
2026-09-05 Add starter parts guidance (motors/controller/camera) + target-practice trainer app
    - hardware §9.1: recommended starter parts. Key point: vision closes the loop + big touch targets => open-loop precision barely matters, pick for cost. Webcam is fine (rigid mount + locked focus + gl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
    - software §5.1: target-practice trainer app as a no-install web page (JS touch events, Tapster-style) doubling as calibration data + accuracy benchmark + optional reward. Honest note: plain closed-l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
2026-09-05 Tune parts guidance for cheap + quiet + not-janky priority
    Quiet is a driver choice: recommend NEMA 17 + TMC2209 (StealthChop2, drop-in for A4988 on the CNC shield, GRBL standalone) and steer away from the janky 28BYJ-48. Add servo-buzz mitigation (own 5V + detach when idle). New §9.1.1 tuned build allocating the ~$50 to TMC2209 drivers + MGN9 rails + regulated PSU; updated cost table + citations.
2026-09-13 Add v1 hardware design + code-CAD scaffold (build123d)
    - specs/01-hardware.md: add §0 FINAL LOCKED DESIGN — belt Cartesian gantry,
    print-max BOM, bronze-oilite bushings on steel rod, retired multi-touch/lead-screw,
    approximate USD + sourced Canadian cost
    - parts/: build123d code-CAD — params, twin-rod X-carriage, single-rod variant,
    color-coded assembly preview (flat two-phone gantry), with fail-fast assert checks
    - parts/aliases.zsh + README: 123_* helpers and workflow
    - .gitignore: ignore generated CAD outputs (stl/step/3mf)
    - remove obsolete STATUS.md handoff
2026-09-13 Add reinforced Y-carriage bracket + solid-build print standard
    - params.py: add reinforcement/print-standard (WALL, FILLET, GRUB_TAP; PETG + 100% infill note)
    and device/tap geometry (DEVICE_H, TAP_STROKE, STYLUS_ADJ, SPRING_TRAVEL)
    - parts/3_y_carriage_bracket.py: solid keystone bracket — Y bushing bore + two X-rod
    bores grub-clamped into a rigid ladder; fail-fast asserts; verified single solid
2026-09-14 Model X-carriage, stylus holder + DEVLOG; retire prototypes
    - parts/1_x_carriage.py: final compact X-carriage (2 press-fit bronze bushing bores,
    top belt-clamp + bottom stylus inserts); verified 1 solid / 1 shell
    - parts/5_stylus_holder.py: first-pass servo/stylus holder (MG90S pocket + spring-loaded
    stylus guide for device-thickness compliance)
    - parts/3_y_carriage_bracket.py: finalized (fillets, heat-set inserts, full-depth rod grip)
    - parts/4_x_motor_bracket.py: plug redundant inserts (no interior voids), NEMA-17 plate
    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
2026-10-02 Add hardware concept v2 (requirements, CoreXY design, parts) + layout model
    - docs/hardware-concept-v2.md: requirements, camera-vs-screen-capture decision,
    CoreXY concept, review of the v1 CAD branch, parts list, sourcing, open questions
    - parts/v2_0_layout.py: envelope layout of the 4-phone CoreXY gantry; checks height
    stack (~48 mm) and stylus/gantry clearance at every screen corner
    [v2_0_layout.py]
2026-10-02 Rebuild v2 layout as real CoreXY; aluminium base; sync parts list
    - Model both CoreXY belts (two planes) with correct pulley wraps, bridge-end and
    corner idlers, toolhead belt clamp; colors match real materials
    - Reach check (carriages stay on rails at every screen corner) + collision sweep
    - Base: 3 mm aluminium plate (JLCCNC, slotted holes) instead of plywood, 6 feet
    - Parts list: rails 420/220, alu flat-bar risers, single 2020 bridge, idler count
    [v2_0_layout.py]
2026-10-02 Log v2 hardware state: verified parts list, idler/motor mounts, DEVLOG entry
    - docs: verified AliExpress/Amazon.ca listings with variants and C$ prices (2026-10-01),
    elsewhere-sourced items, assembly notes, USB-only controller security, open question 6
    - layout: idler bolts clamped top+bottom (corner walls/top plates, bridge-end top plates),
    motor clamp bars + legs, bridge rail 230 mm (stock length); height 5.0 cm, checks pass
    - DEVLOG: dated entry summarising the v2 proposal and next steps
2026-10-02 Split repo by owner (aria/ hardware, marc/ software); adopt 2-phone plan
    - Move Aria's work to aria/ (concept doc, LOG.md, cad/v2_0_layout.py) and Marc's
    v1 CAD + DEVLOG to marc/ (parts-v1/); READMEs for each; root README map + status
    - Concept doc: 2-phone capacity (test with 1), ~34x32x5 cm, rails 230 mm x3,
    ~C$325 + tax split between us, work-sourcing columns, exposed-parameter table
    - Layout model sizes the frame from N_PHONES (stock rail length -> motors -> base)
    - .gitignore: ignore generated STL/STEP/3MF anywhere
2026-10-05 research: format all notes with Obsidian frontmatter, fill gaps, add vault
    - Reformatted 01-prior-art, 02-mechanical, 05-ai-agent to TEMPLATE format
    - Added 06-vlm-gui-agent-survey (VLM GUI agents, vision grounding)
    - Added 07-ios-control-constraints (Face ID, autofill, accessibility)
    - Added 08-xy-gantry-builds (gantry builds, microcontroller choice)
    - Added yolo-training/ subdirectory with 3 research notes
    - Added TEMPLATE.md, questions.md running question log
    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
2026-10-06 research: reorganize vault into domain folders, add Home/Timeline
    - Grouped research into domain subdirectories:
    mechanical/ (prior art, touch physics, gantry/microcontroller)
    ios-control/ (Face ID, autofill, AssistiveTouch, cursor calibration)
    agent-ml/ (AI architecture, VLM GUI agent survey)
    _side-projects/ (tennis modeling, gambling detection — not the robot)
    - Added Home.md (Map of Content, canonical entry point)
    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
2026-10-06 research: fix all frontmatter — every note links to exactly one central node
    - Physical notes → Hardware Central
    - ML notes → ML Central
    - System notes → Software Central
    - Development Central (timeline, standalone)
    - Side projects (sports, gambling) intentionally disconnected
    - TEMPLATE.md intentional orphan
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2026-10-07 replace Development Central with Storyline chain, add Meeting 1, all hardware verified attached
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2026-10-08 Reconnect orphaned notes: fill dead link stubs, add Related footers
    - Fill 41 empty link stubs left from the original restructure (older YOLO,
    iOS Control, Betting Apps notes) and fix dangling sentences
    - Every research note gets a Related footer linking its State-of summaries;
    summaries cross-link each other
    - Former orphans (Regulatory, Prior Art) linked from summaries + siblings
    - Result: no orphans, no dead ends, every note has >= 3 links
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2026-10-10 Add JLCCNC base plate: 340.6x320x3 mm, 40 slotted M3 holes, from layout dims
    base_plate.py derives every hole from v2_0_layout.py and checks edge distance,
    hole spacing and footprint clashes (none). Exports DXF for the laser quote,
    STEP (gitignored, regenerate) and an SVG preview with part footprints.
    [base_plate.dxf]
2026-10-11 Log plate order (C$51.73), swap riser bar to 10x10 6061, add wiring/tools from work
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
